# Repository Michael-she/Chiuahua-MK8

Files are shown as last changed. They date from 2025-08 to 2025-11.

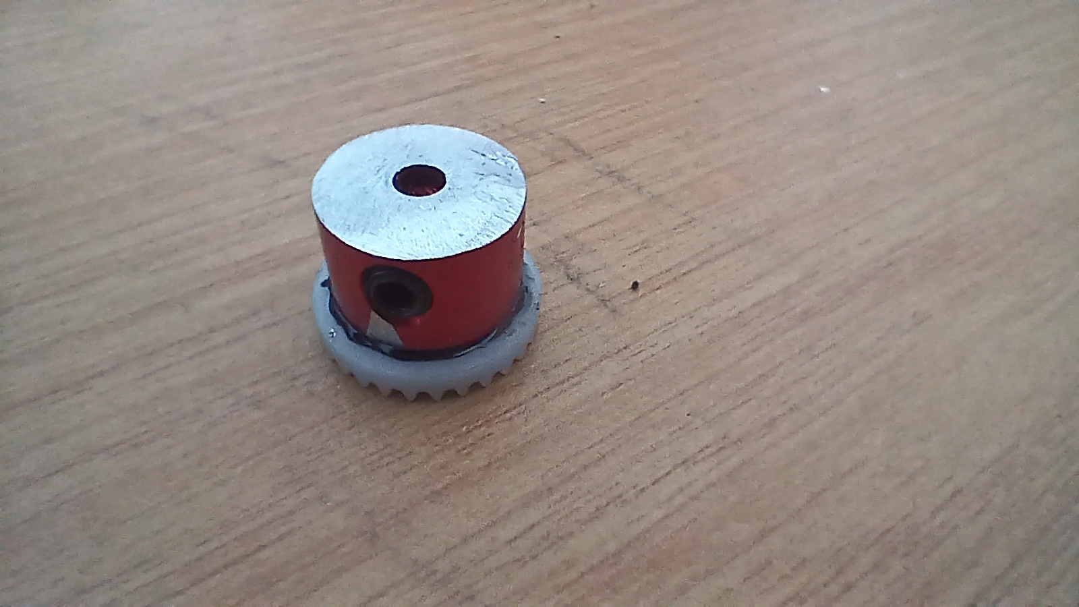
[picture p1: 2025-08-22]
Vehicle-Photos/All/20250713_171845.jpg

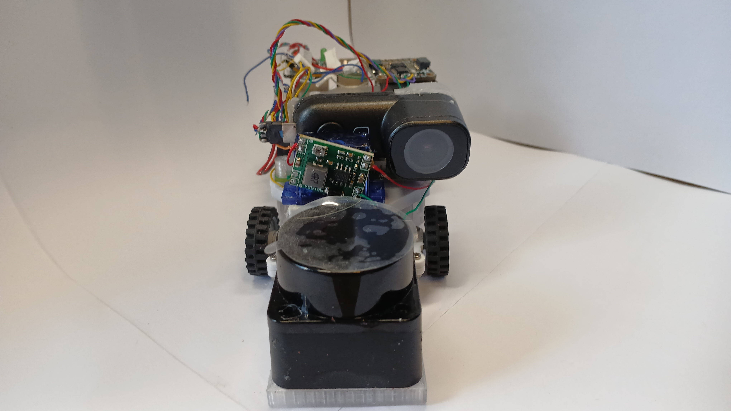
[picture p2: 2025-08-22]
Vehicle-Photos/All/20250822_122142.jpg

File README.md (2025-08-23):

# Chiuahua-MK8 - WRO 2025 Future Engineers Category

Welcome to the Chiuahua-MK8 repository! This project contains all the development work for our autonomous vehicle designed for the World Robot Olympiad (WRO) 2025 competition.

## 📖 Engineering Journal

**👉 Start here: [WRO 2025 Engineering Journal](./Engineering%20Journal/WRO%202025%20JOURNAL.pdf)**

The engineering journal is the comprehensive documentation of our entire development process, design decisions, testing results, and project evolution. It provides detailed insights into:
- Design methodology and iterations
- Technical challenges and solutions
- Testing protocols and results
- Team collaboration and project timeline

## 🗂️ Repository Structure

### 📁 **Engineering Journal/**
Contains the main project documentation:
- `WRO 2025 JOURNAL.pdf` - Complete engineering documentation and project narrative

### 💻 **SRC/** - Source Code
Main codebase for the autonomous vehicle:
- `camera/` - Computer vision and image processing modules
- `final/` - Production-ready code and main control systems
- `gyro/` - Gyroscope sensor integration and orientation tracking
- `lidar/` - LiDAR sensor drivers and obstacle detection
- `motor/` - Motor control and movement systems
- `servo/` - Servo motor control for steering mechanisms
- `Simulation/` - Testing and simulation environments
- `The Taxi/` - Specific challenge implementation code
- `.venv/` - Python virtual environment for dependency management

### 🔧 **3D Models/** - Mechanical Design
CAD files and 3D printable components:
- `STEP/` - Standard 3D model files for manufacturing
- `V1/` - First iteration designs and prototypes
- `V2/` - Second iteration improvements and refinements

### 📋 **3D Printing Profiles/**
Optimized printing settings and profiles for manufacturing vehicle components

### ⚡ **Circuit Schematics/**
Electrical system documentation:
- `Power Map.svg` - Power distribution and electrical layout
- `Schematic_WRO-2025_2025-08-22.svg` - Complete circuit diagrams

### 📸 **Team-Photos/**
Documentation of team members and collaboration

### 🚗 **Vehicle-Photos/**
Visual documentation of the physical vehicle and its development stages

## 🚀 Getting Started

1. **Read the Engineering Journal** - Start with the PDF in the `Engineering Journal/` folder for complete project context
2. **Explore the Code** - Check out the `SRC/` directory for the software implementation
3. **Review Designs** - Look at `3D Models/` and `Circuit Schematics/` for hardware details
4. **See the Vehicle** - Browse `Vehicle-Photos/` to see the physical implementation

## 🛠️ Development Environment

This project uses Python for the main control software. The virtual environment is set up in `SRC/.venv/` with all necessary dependencies.

## 📋 Competition Context

This repository represents our complete solution for the WRO 2025 autonomous vehicle challenge, including:
- Autonomous navigation and obstacle avoidance
- Computer vision for environmental perception
- Sensor fusion for robust decision making
- Real-time control systems for vehicle operation

## 📞 Team Contact

For questions about this project or collaboration opportunities, please contact:
Michael Shepstone - mgshepstone+wrofe@gmail.com
Siobhan Kennedy - skenn23@gmail.com

---

**Note**: This repository contains the complete development history and documentation for educational and reference purposes. The Engineering Journal provides the most comprehensive overview of the project methodology and results.

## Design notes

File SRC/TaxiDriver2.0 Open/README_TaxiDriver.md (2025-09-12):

# Taxi Driver API Documentation

## Overview
The `TaxiDriver` class provides a high-level interface to control a motor using multiprocessing for communication with the motor controller hardware. It uses `multiprocessing.Value` objects for thread-safe communication between the main process and the motor controller process.

## Key Features
- **Motor Speed Control**: Set speed from 0-100%
- **Direction Control**: Forward, reverse, or stop
- **Encoder Feedback**: Real-time encoder count reading
- **Multiprocessing**: Separate process handles GPIO operations
- **Thread-Safe**: Uses multiprocessing.Value for safe data sharing

## Quick Start

```python
from taxi_driver import TaxiDriver
import time

# Initialize taxi driver
taxi = TaxiDriver()
taxi.start_motor_controller()
time.sleep(2)  # Allow initialization

# Basic motor control
taxi.move_forward(50)        # Move forward at 50% speed
time.sleep(2)
taxi.move_reverse(30)        # Move reverse at 30% speed
time.sleep(2)
taxi.stop_motor()            # Stop motor

# Get encoder reading
encoder_count = taxi.get_encoder_reading()
print(f"Encoder count: {encoder_count}")

# Cleanup when done
taxi.cleanup()
```

## API Reference

### Initialization

#### `TaxiDriver()`
Creates a new TaxiDriver instance with multiprocessing communication setup.

```python
taxi = TaxiDriver()
```

#### `start_motor_controller()`
Starts the motor controller process. Must be called before motor operations.

```python
taxi.start_motor_controller()
```

#### `stop_motor_controller()`
Stops the motor controller process. Called automatically by cleanup().

```python
taxi.stop_motor_controller()
```

### Motor Control

#### `set_motor_speed(speed_percent)`
Set motor speed as a percentage.

**Parameters:**
- `speed_percent` (float): Speed from 0-100

```python
taxi.set_motor_speed(75)  # Set to 75% speed
```

#### `set_motor_direction(direction)`
Set motor direction.

**Parameters:**
- `direction` (int): 1=forward, -1=reverse, 0=stop

```python
taxi.set_motor_direction(1)   # Forward
taxi.set_motor_direction(-1)  # Reverse
taxi.set_motor_direction(0)   # Stop
```

#### `move_forward(speed_percent)`
Move forward at specified speed.

**Parameters:**
- `speed_percent` (float): Speed from 0-100

```python
taxi.move_forward(60)  # Move forward at 60% speed
```

#### `move_reverse(speed_percent)`
Move reverse at specified speed.

**Parameters:**
- `speed_percent` (float): Speed from 0-100

```python
taxi.move_reverse(40)  # Move reverse at 40% speed
```

#### `stop_motor()`
Stop the motor immediately.

```python
taxi.stop_motor()
```

### Sensor Reading

#### `get_encoder_reading()`
Get current encoder count.

**Returns:**
- `int`: Current encoder count

```python
count = taxi.get_encoder_reading()
print(f"Encoder: {count} counts")
```

### Status Information

#### `get_motor_status()`
Get comprehensive motor status.

**Returns:**
- `dict`: Status dictionary with keys:
  - `speed`: Current speed percentage
  - `direction`: Direction value (-1, 0, 1)
  - `direction_text`: Human-readable direction
  - `encoder_count`: Current encoder count
  - `status`: Combined status string

```python
status = taxi.get_motor_status()
print(f"Motor: {status['status']}")
print(f"Encoder: {status['encoder_count']}")
```

### Utility Functions

#### `run_test_sequence()`
Run a predefined test sequence demonstrating motor control.

```python
taxi.run_test_sequence()
```

#### `interactive_control()`
Start interactive command-line control interface.

```python
taxi.interactive_control()
```

#### `cleanup()`
Clean up resources and stop motor controller process. Should always be called when done.

```python
taxi.cleanup()
```

## Example Usage Patterns

### Basic Control Loop
```python
taxi = TaxiDriver()
taxi.start_motor_controller()
time.sleep(2)

try:
    # Control loop
    for speed in [25, 50, 75, 100]:
        taxi.move_forward(speed)
        time.sleep(1)
        encoder = taxi.get_encoder_reading()
        print(f"Speed: {speed}%, Encoder: {encoder}")
    
    taxi.stop_motor()
    
finally:
    taxi.cleanup()
```

### Encoder-Based Movement
```python
taxi = TaxiDriver()
taxi.start_motor_controller()
time.sleep(2)

try:
    # Move until encoder reaches certain count
    target_encoder = taxi.get_encoder_reading() + 1000
    taxi.move_forward(50)
    
    while taxi.get_encoder_reading() < target_encoder:
        time.sleep(0.1)
    
    taxi.stop_motor()
    print(f"Reached target encoder: {taxi.get_encoder_reading()}")
    
finally:
    taxi.cleanup()
```

## Hardware Configuration

The motor controller is configured for:
- **Motor Control Pins**: GPIO 20, 21 (PWM control)
- **Encoder Pins**: GPIO 19, 13 (quadrature encoder)
- **PWM Frequency**: 2000 Hz

## Error Handling

Always use try/finally blocks to ensure cleanup:

```python
taxi = TaxiDriver()
try:
    taxi.start_motor_controller()
    # Your control code here
finally:
    taxi.cleanup()
```

## Multiprocessing Details

The `TaxiDriver` uses `multiprocessing.Value` objects for communication:
- `motor_speed`: Double precision float (0-100)
- `motor_direction`: Integer (-1, 0, 1)
- `encoder_value`: Integer (encoder count)
- `shutdown_flag`: Integer (process control)

This design ensures thread-safe communication and isolates GPIO operations in a separate process.

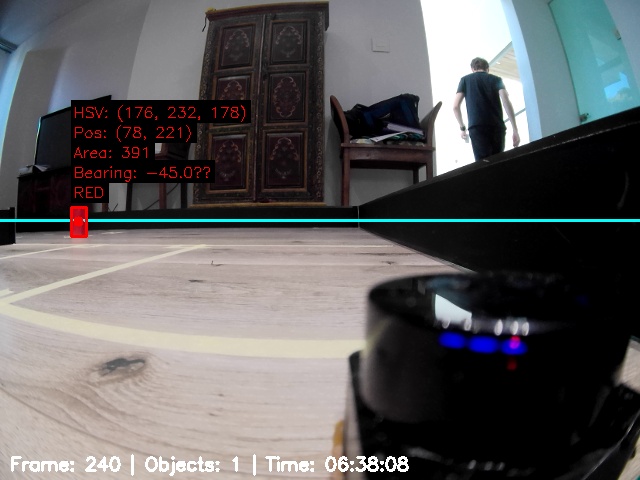
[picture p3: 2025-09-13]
SRC/TaxiDriver4.0 Obstacle/camera_captures/annotated_frame_20250913_063808_000240.jpg

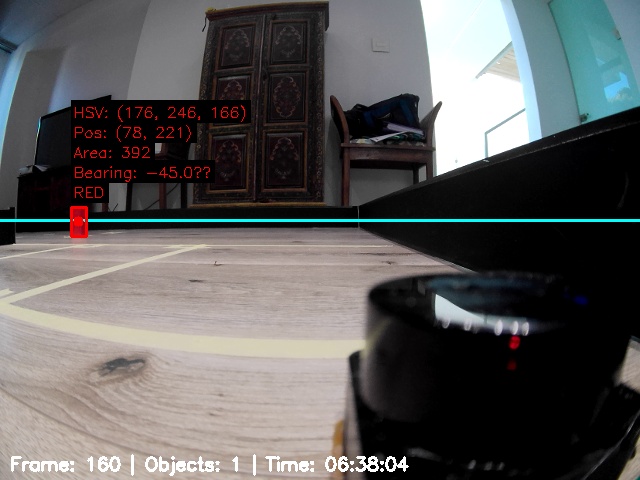
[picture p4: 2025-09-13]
SRC/TaxiDriver4.0 Obstacle/camera_captures/annotated_frame_20250913_063804_000160.jpg

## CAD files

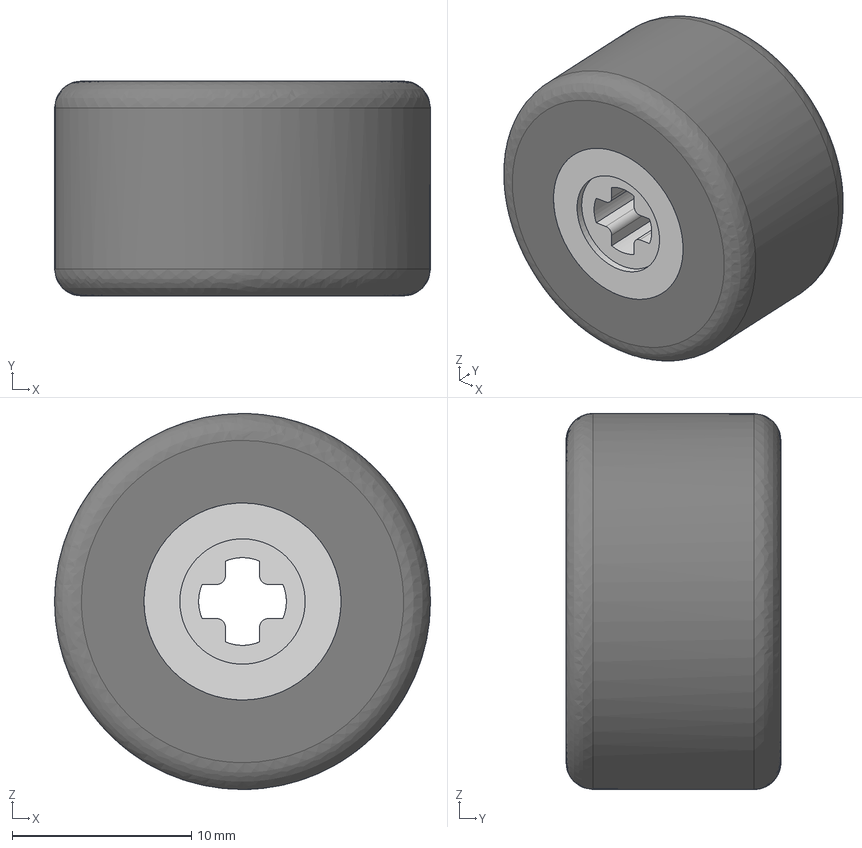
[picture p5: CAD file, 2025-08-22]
3D Models/STEP/Wheel complete v2.iges
21.0 x 12.0 x 21.0 mm

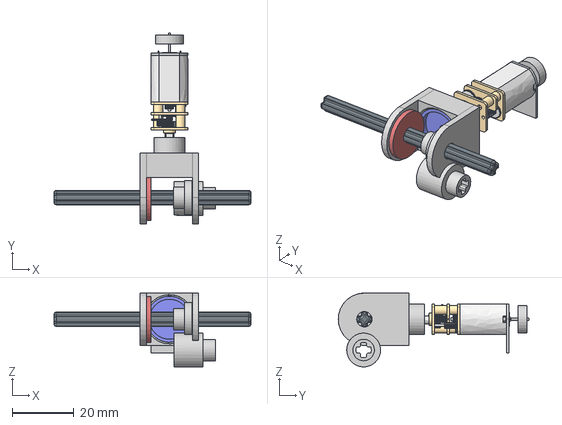
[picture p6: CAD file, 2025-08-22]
3D Models/STEP/Gearbox v15.iges
64.0 x 61.9 x 24.0 mm

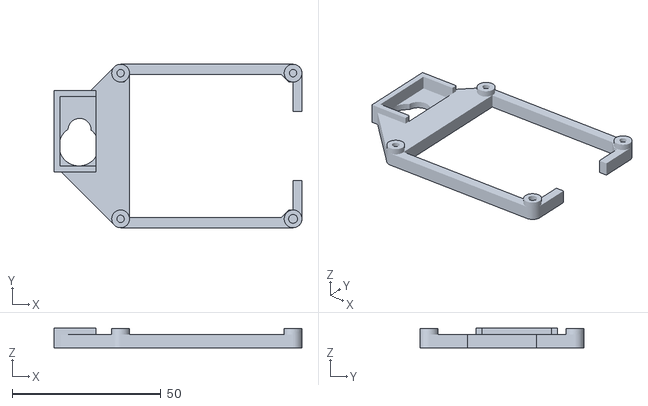
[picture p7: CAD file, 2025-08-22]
3D Models/V2/Pi mount top (2).stl
83.4 x 55.0 x 6.70

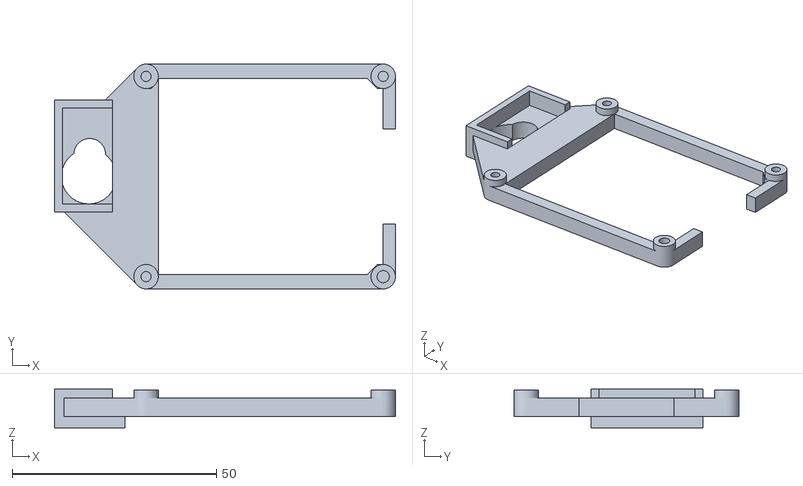
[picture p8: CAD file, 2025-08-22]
3D Models/V2/Pi mount.stl
83.4 x 55.0 x 9.50

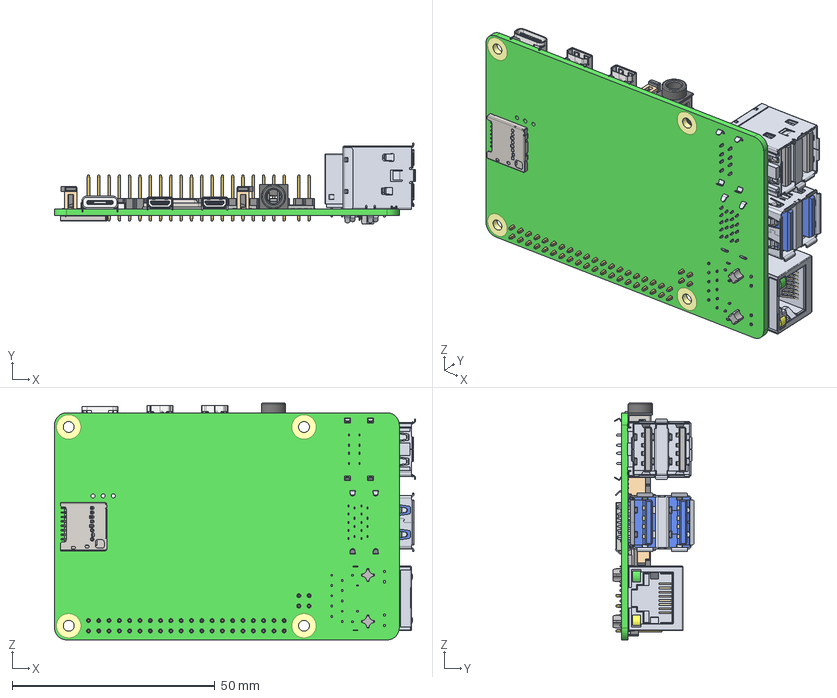
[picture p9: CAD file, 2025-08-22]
3D Models/STEP/Raspberry Pi 4 Model B v1.step
89.0 x 19.9 x 58.4 mm
PCB, RPi4ModelB
Broadcom BCM2711B0 CPU, RPi4ModelB
2.54 mm DUPONT MALE PIN HEADER, POE, 2X2, RPi4ModelB
2.54 mm DUPONT MALE PIN HEADER, IO, 2X20, RPi4ModelB
Camera Connector, RPi4ModelB
Microphone Plug, RPi4ModelB
Display Connector, RPi4ModelB
Gigabit Ethernet Port, RPi4ModelB
Female Micro HDMI Connector, RPi4ModelB x 2
Female USB Type C Connector, RPi4ModelB
2X USB3.0 PORTS, RPi4ModelB
91D77 D9WHV 778K, 4 GB LPDDR4 SDRAM, RPi4ModelB
Cypress CYW43455 Wireless Module Cover, RPi4ModelB
SD Card Slot, RPi4ModelB
VIA VL805 PCIe USB 3.0 controller, RPi4ModelB
2X USB2.0 PORTS, RPi4ModelB
Broadcom BCM54213PE Gigabit Ethernet Transceiver, RPi4ModelB
MxL7704 Universal PMIC, RPi4ModelB

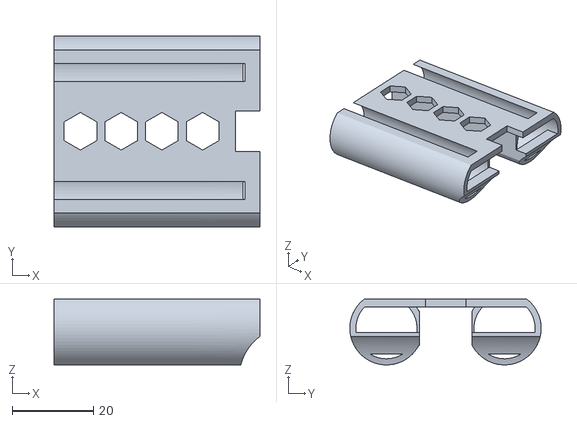
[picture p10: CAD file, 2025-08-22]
3D Models/V2/Battery Holder.stl
50.6 x 47.0 x 16.2

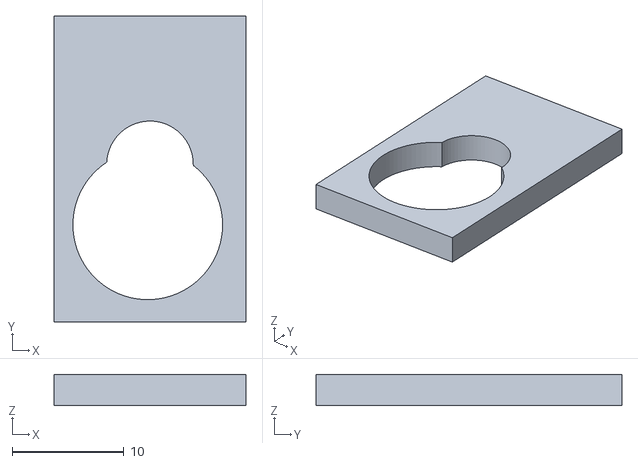
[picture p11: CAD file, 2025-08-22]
3D Models/V2/Pi mount bottom.stl
17.2 x 27.4 x 2.80

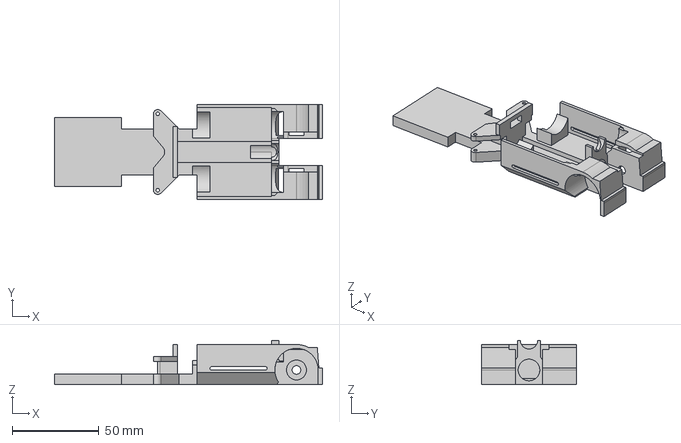
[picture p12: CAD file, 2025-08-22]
3D Models/V2/Frame Unibody.step
154.5 x 55.0 x 25.6 mm

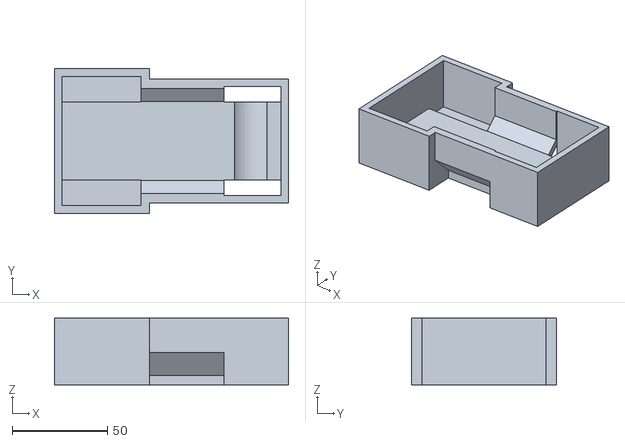
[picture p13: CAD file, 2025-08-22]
3D Models/V2/Component10.stl
122.9 x 76.0 x 35.0

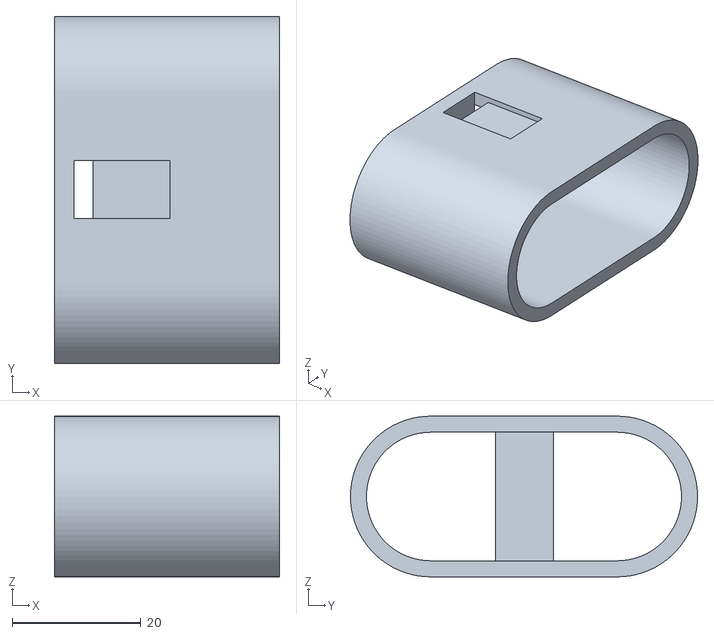
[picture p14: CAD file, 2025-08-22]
3D Models/V2/Battery charger.stl
35.0 x 54.0 x 25.0

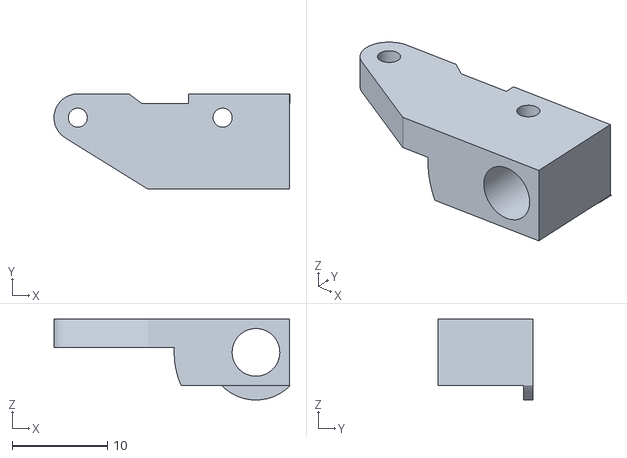
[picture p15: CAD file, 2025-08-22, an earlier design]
3D Models/V1/Front wheel mount.stl
24.8 x 10.0 x 8.50

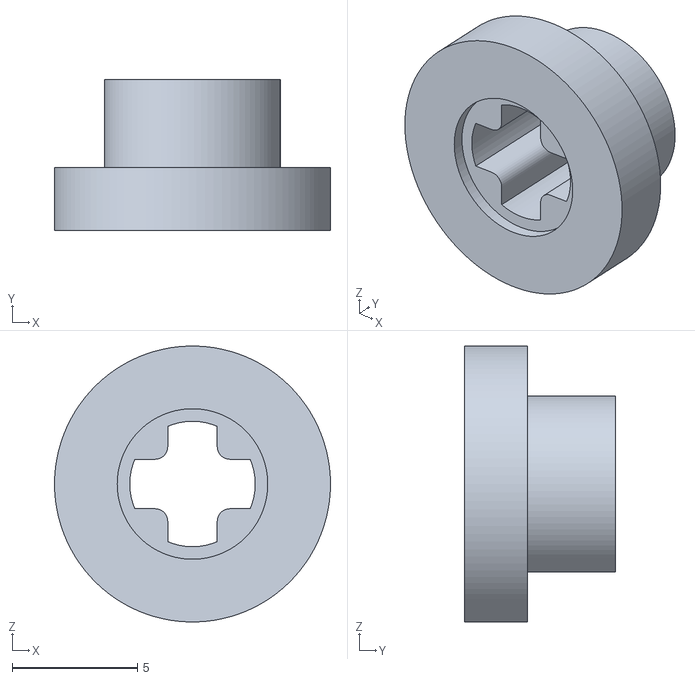
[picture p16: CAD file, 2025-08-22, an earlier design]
3D Models/V1/Gearbox/Axle Gear support type 1 v7.stl
11.0 x 6.00 x 11.0

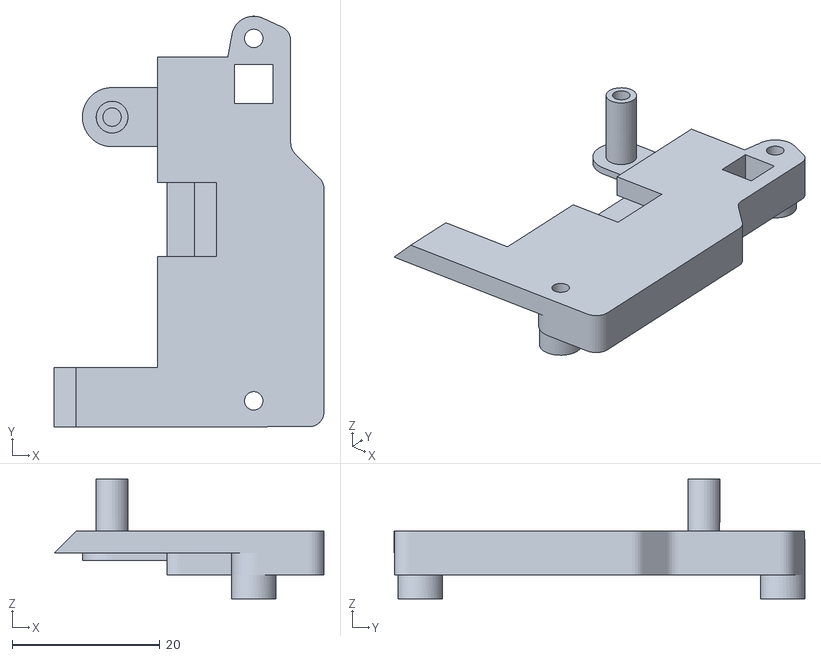
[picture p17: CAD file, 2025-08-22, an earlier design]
3D Models/V1/Top Frame/Body5.stl
36.5 x 55.5 x 16.2

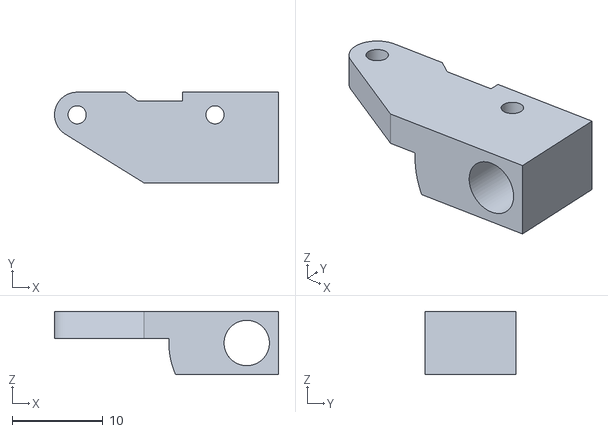
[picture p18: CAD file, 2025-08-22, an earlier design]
3D Models/V1/Front wheel mount R.stl
24.7 x 10.0 x 7.00

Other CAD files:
3D Models/V1/Gearbox/Gearbox casing.stl
3D Models/V1/Top Frame/Body6.stl
3D Models/V1/Battery Holder.stl
3D Models/V1/Gearbox/Motor Shaft.stl
3D Models/STEP/13500 cell v1.f3d
3D Models/STEP/Battery Holder.f3d
3D Models/STEP/Frame Unibody.f3d
3D Models/STEP/Front wheel mount R.f3d
3D Models/STEP/Front wheel mount(Mirror).f3d
3D Models/STEP/Motor Driver.f3d
3D Models/STEP/OKDO Lidar v2.f3d
3D Models/STEP/Pi mount.f3d
3D Models/STEP/RunCam Thumb v4 v1.f3d
3D Models/STEP/Steering bar.f3d
3D Models/STEP/Upper frame.f3d
3D Models/STEP/Wheel 2 v1(Mirror).f3d
3D Models/STEP/Wheel 2 v1.f3d
3D Models/STEP/microservoAssembly v3.f3d
3D Models/V1/Body19.stl
3D Models/V1/Component5.stl
3D Models/V1/Component6.stl
3D Models/V1/Frame Unibody.stl
3D Models/V1/Front wheel mount(Mirror).stl
3D Models/V1/Pi mount top.stl
3D Models/V1/Steering bar.stl
3D Models/V1/Top Frame/Body10.stl
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

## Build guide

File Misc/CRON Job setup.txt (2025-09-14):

Go and create the CRON JOB To run on reboot. 
Run the command
>> crontab -e

Add line in the format:
@rebo1ot [path to python], [path to script]

    @reboot /usr/bin/python3 /home/ubuntu/active/taxi_navigator.py >> /logs/logfile.log 2>

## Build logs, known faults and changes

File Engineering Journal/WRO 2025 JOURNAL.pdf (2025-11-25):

# WRO 2025 ENGINEERING JOURNAL

# Future Engineers

# Team: NullPointerException

# Contents

# Introduction

Welcome to team NullPointerException’s Engineering Journal. This document will guide you through our process of designing, building and programming our robot. Along with this will be demonstration videos of the final version, pictures, and step by step instructions for its assembly.

This year’s Self-Driving Car challenge features a reintroduction of the randomisation process, a removal of the need to turn around in the last round, and adjusted rules concerning parallel parking. Basing our current robot off its counterpart used in last year’s challenge, this document will describe the revisions and reworks we have applied to comply with the added features of the challenge, as well as improve its overall functionality.

# The Team

We are a South African team, made up of:

❖ Michael Shepstone (20) - studying Mechatronic Engineering

❖ Siobhan Kennedy (20) - studying Computational Linguistics

❖ Jarred Williams - our coach

And of course, Chihuahua (the robot).

Chihuahua has seen many improvements and evolutions over the last three years of partaking in the World Robotics Olympiad’s Future Engineers category, with this document describing its latest version, version 8.5.

Coming out of last year’s competition, we learnt numerous lessons and brought new ideas to the table on how to improve our robot this time around. Ultimately, we decided to go back to the drawing board for the most part. In our mission to rehaul the robot, we discovered more efficient ways to make the robot function better, while also learning several important lessons, which are elaborated on throughout the document.

Michael Shepstone and Siobhan Kennedy

## “Chihuahua” Mk8

Picture 1: Front view | Picture 2: Back view
Picture 3: Left side view | Picture 4: Right side view
Picture 5: Top view | Picture 6: Bottom view

# Mobility Management

## POWERTRAIN

### Wheels and Tyres

We used Lego rubber tyres (part number 60700) for the back wheels, and Lego rubber wheels and hubs (part numbers 61254 and 56902) for the front wheels. We learned that the wheels needed to be rubber for better grip and to avoid slipping. Lego makes rubber wheels that were perfectly suited to the adjustments we wanted to make.

The tyres used for the back wheels were chosen due to their large width-to-diameter ratio, as well as their good grip. This ensures that the robot can remain sturdy while travelling across the surface and prevent any slipping. For whatever reason, lego makes no wheel hub for this particular tyre that can fit an L-series axle, thus we had to design and print our own.

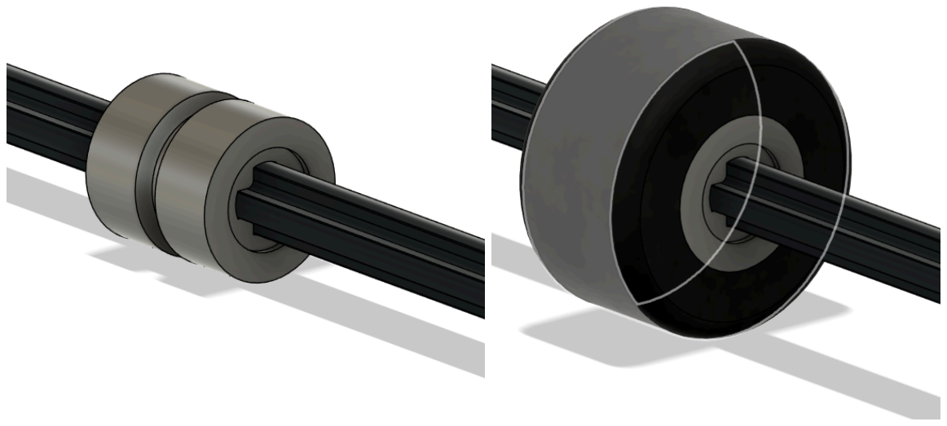
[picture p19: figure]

Diagram 1 & 2: Wheel adaptor on shaft, without and with tyre

The tyres we used for the front wheels are relatively narrow, which causes high loading, which in turn reduces the clearance required for the robot to be able to steer smoothly. These wheels rotate freely.

### Gearbox and Drivetrain

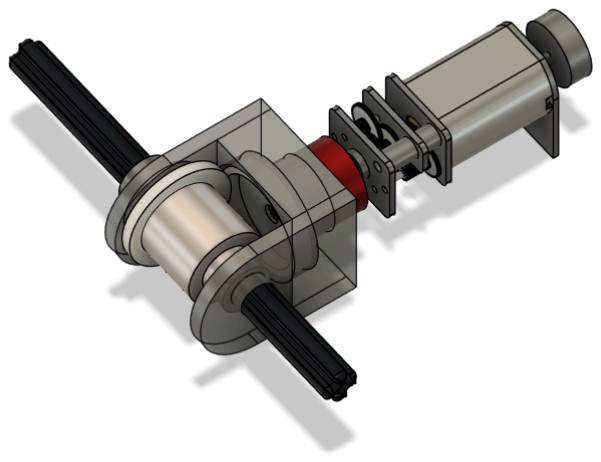
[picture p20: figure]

Diagram 3: CAD Model of the complete motor-gearbox-axle assembly

The robot’s drivetrain currently consists of a lego L-series axle, and two gears that transfer the power by 90 degrees. To achieve this, the motor coupler has been cut in half, with the gear glued to it. This gear then meshes with a separate gear at a 90 degree angle to it. This second gear transfers the motion to the axle.

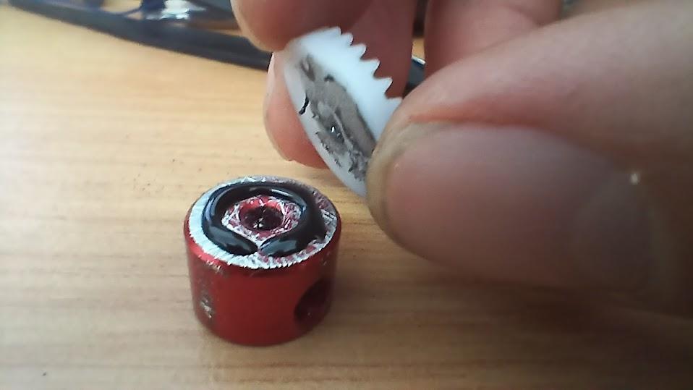
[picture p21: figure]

Picture 7: Attaching the gear to the halved motor coupler

Based on previous versions of the robot, we learned that ultimately, it was best to keep the wheel and axle system simple. We also previously attempted using a differential gearbox, but found that it was too large, and could easily cause problems should a wheel break ground contact.

### Motor

Diagram 4

After considering various different motors, we settled on an N20 motor with an 800 rpm gearbox, (https://www.robotics.org.za/N20-800RPM-KIT?search=N20) with the following specifications:

- Voltage: 12V
- Weight: 9.5g
- Gear Ratio: 1:50
- Speed: 650 ± 31% rpm
- Torque: 0.67 ± kg∙cm

Other motors we considered include:

- Micro Stepper motors – Very precise, easy to drive with good power output, but was too large and outside the
required RPM range.
- Where to buy the motor:

https://www.robotics.org.za/index.php?route=product/product&product_id=1438&search=stepper (https://www.robotics.org.za/index.php?route=product/product&product_id=1438&search=stepper)

- 130 Size DC Motors – Cheap and easy to obtain, with many pre-assembled attachments, but ended up being too underpowered and electronically noisy. Plus, it would have required an additional gearbox in any case.
- Where to buy the motor:

https://www.robotics.org.za/DC-MOTOR-6V?search=6v

- 25mm DC Motors – Good power output with an included gearbox, the motor of choice for previous robots, but ended
up being too large in this case.
- Where to buy the motor:

https://www.robotics.org.za/25GM370-060-12V?search=DC%20motor

Ultimately, we decided on the N20 800rpm motor for its lightweight and compact design. As this motor did not come with an encoder attached, we ended up using a 15rpm motor with the 800rpm motor transferred onto it.

Our encoder of choice is a Hall-effect magnetic encoder, which offers high precision and encodes direct motor output. In order to fit it into our robot, it had to be filed down, and the connector had to be removed with wires soldered directly to the PCB.

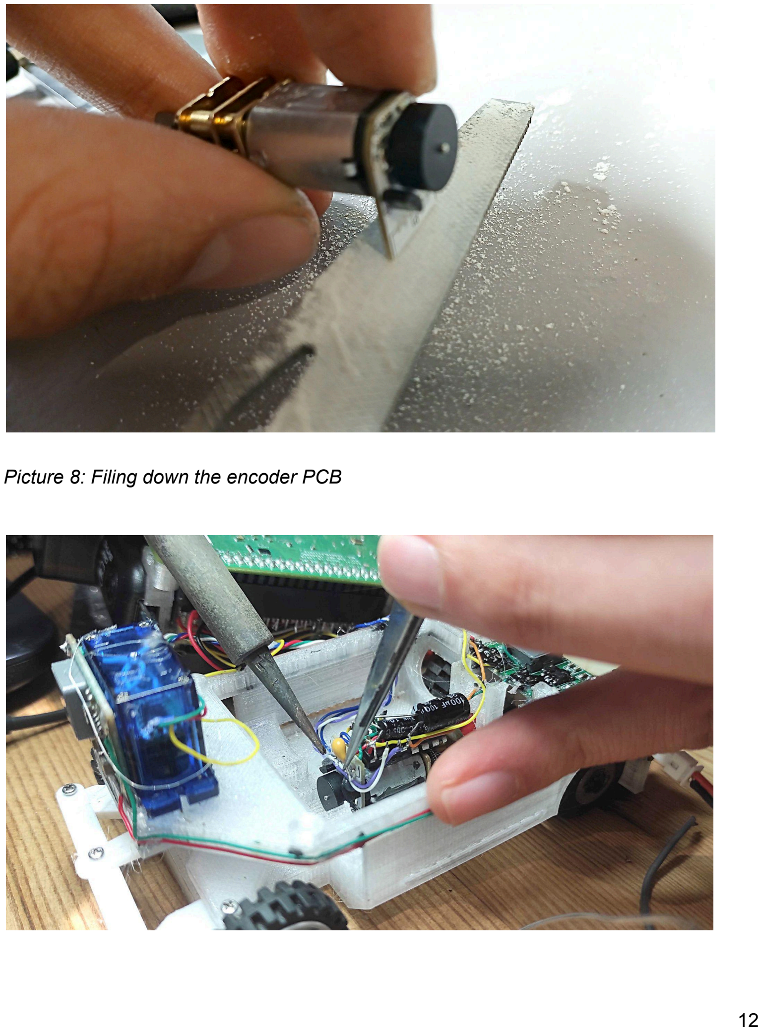
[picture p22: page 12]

Picture 8: Filing down the encoder PCB

Picture 9: Soldering wires to the motor and motor driver

This motor connects directly to the aluminium motor coupler that is glued to the gear. The motor shaft is secured in place with a grub screw, instead of glue. Not only does this allow for a slight tolerance in the placement of the motor, but it also allows for parts to be swapped out, should it be necessary.

The previous iteration of this robot had a 3D printed driveshaft, which ended up proving to be problematic as it was prone to stripping or shearing. Therefore, based on the lessons learnt, all of our driveshafts are made of injection molded, or metallic components.

### Motor Driver

For this iteration of the robot, we elected to use the MX1919 motor driver chip, (https://www.robotics.org.za/MAX1919-DIP?search=MX1919) with the following specifications:

- Power Supply Voltage:
- Min: 2V
- Max: 9.6V
- Logic and Control Supply Voltage:
- Min: 1.8V
- Max: 5V
- Integrated Bridge Drive Circuit

The chip was attached to the motor backwards, and wires were soldered directly to the driver. Its feet were also clipped short for spatial efficiency.

A very important lesson we learned from this part of the assembly process was that the motor driver must be wired with capacitors in order to prevent accidentally blowing the chip. We will not be disclosing how we discovered this, but you can probably guess.

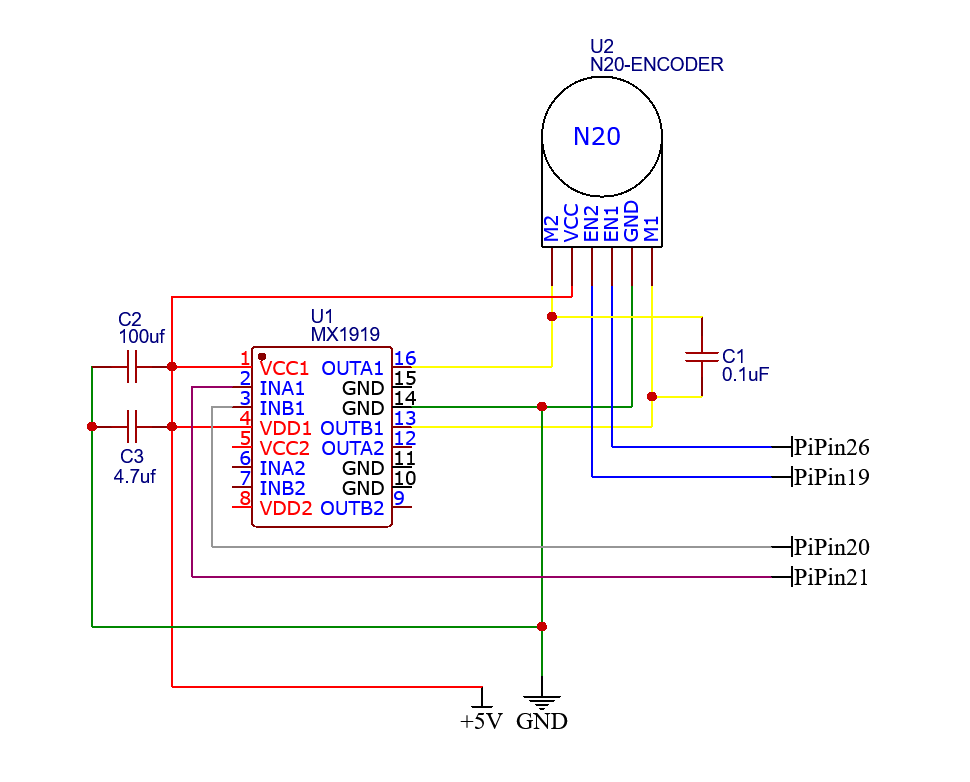
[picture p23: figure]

Diagram 5: Schematic for motor driver

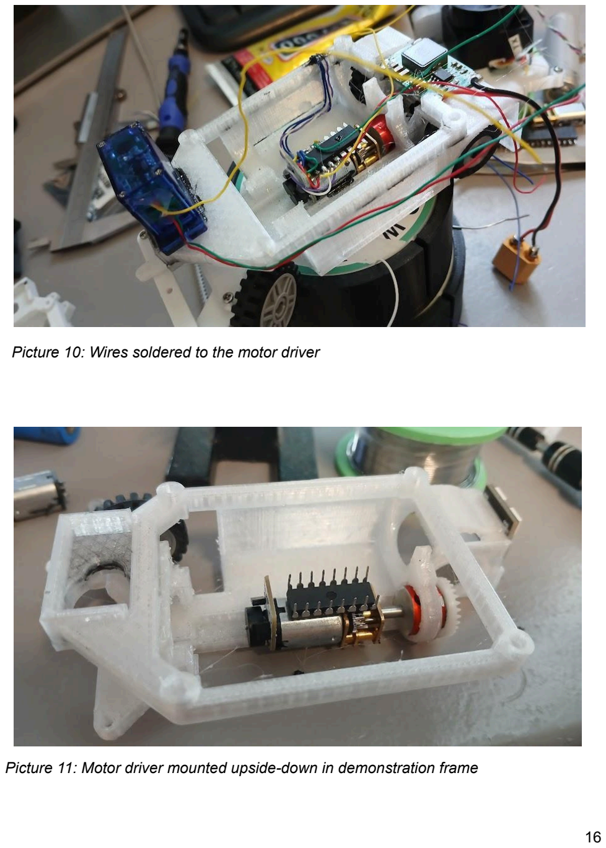
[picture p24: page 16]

Picture 10: Wires soldered to the motor driver

Picture 11: Motor driver mounted upside-down in demonstration frame

## STEERING

### Motor

For our steering motor, we opted to use the FS90 9g Analog Servo, (https://www.robotics.org.za/FS90?search=Servo) with the following specifications:

- Closed loop (180 degrees)
- Torque: 6V:1.5 kg∙cm
- Operating Voltage: 4.8V - 6V
- Speed: 6V:0.10 sec/60°
- Size: 23.2 * 12.5 * 22.0mm

Ultimately, we chose this motor for its positional encoding. Additional factors include its cost efficiency, ample library support, and more-than-sufficient power output required to drive the steering system. At one point we considered using a stepper motor for its precision, but decided against it. In comparison to the servo motor, the stepper motor is slower, and requires a “homing” sequence (or some other form of external encoder) in order to learn its position. This is less effective than the positional encoding of the servo.

### Mechanism

For last year’s competition, the robot used an “all wheel” steering system which, while getting the job done at the time, proved to be problematic. This year, we circumnavigated these issues by employing a simple “front wheel only” steering system instead.

Based on previous experience, we knew from the start that minimising the turning radius would be vital to the success of the robot. The “all wheel” system used in previous versions of the robot was simply not worth the complexity and the single points of failure it caused, and thus, another method was needed.

To accomplish this, the robot now uses a steering bar driven by the arm of the servo to manipulate the front wheel mounts, so that they can move left and right with a ± 45 degree angle of steering. The linkages are made using m1.5 bolts and nuts, the latter of which are secured with hot glue to prevent vibrations from losing them and adding “slop” to the mechanism.

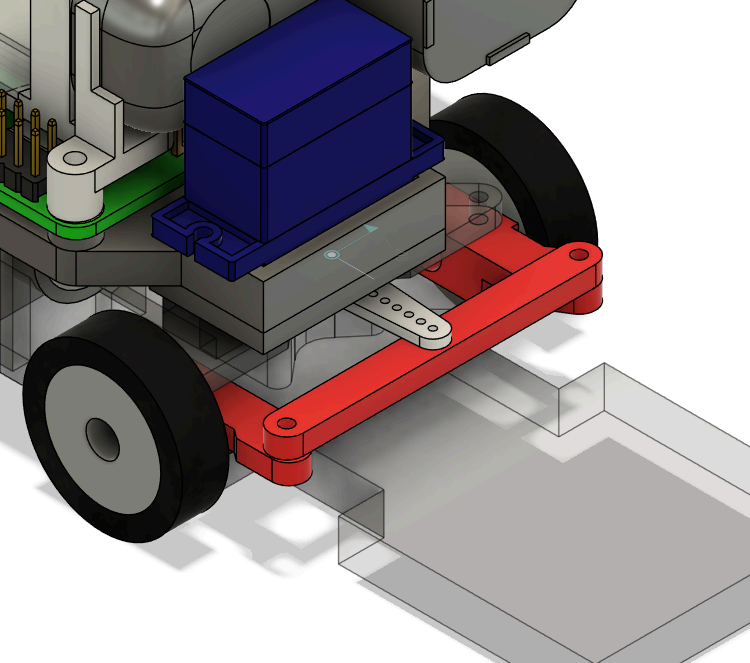
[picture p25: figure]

Diagram 6: Simplified steering mechanism highlighted in red

### Wheel Base

The final turning radius of a robot is directly proportional to the wheelbase of a robot, therefore this must be kept to an absolute minimum, the wheelbase of this robot is 70mm, which is tiny compared to the 110mm wheelbase of the previous iteration. This was achieved by shrinking the entire robot, and packing components as close together as possible, internally. Additionally, only components that were physically unable to be placed elsewhere were put between the front and back wheels.

### Wheel Separation

Due to the lack of a differential drive, the back wheels spin at the same speed, resulting in one being “dragged” over the mat when the robot is turning. Therefore, the distance between these wheels needs to be kept to a minimum in order to minimise the moment of torque this creates.

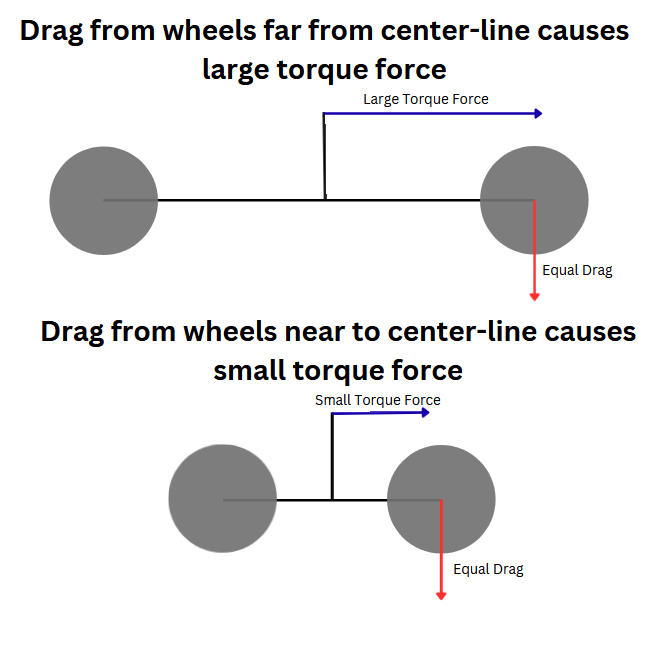
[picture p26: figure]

Diagram 7: Reasoning for chosen distance between wheels

Conversely, the distance between the front wheels must be maximised relative to this, to maximise the torque they put on the robot to turn it, ensuring that the robot turns properly when commanded to do so.

## CHASSIS

The chassis of our robot is entirely 3D printed from a mixture of PTEG and PTA filament, with PTEG (chosen for its resistance to becoming brittle, high strength and relative ease of printing) being used for the major components, and PTA (used for its high dimensional accuracy, and ease of printing) being used for smaller and non-critical components.

The chassis consists of two main layers: above and below the Raspberry Pi. The Raspberry Pi, spanning the full width of the robot and the majority of the usable length, essentially splits the robot in two.

The main unibody frame is printed as a single piece, simplifying the robot and reducing the required assembly. This frame houses the motor, motor driver, and the battery pack. It provides mounting points for the steering servo, LiDAR, voltage regulators, and the Raspberry Pi.

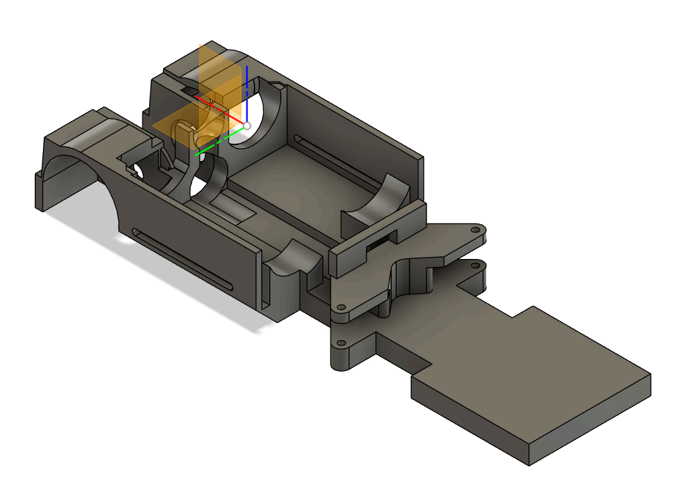
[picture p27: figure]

Diagram 8: Main frame

There are still some pieces that need to be assembled to create the main frame. These parts were separated to remove large overhangs that would otherwise need to be printed.

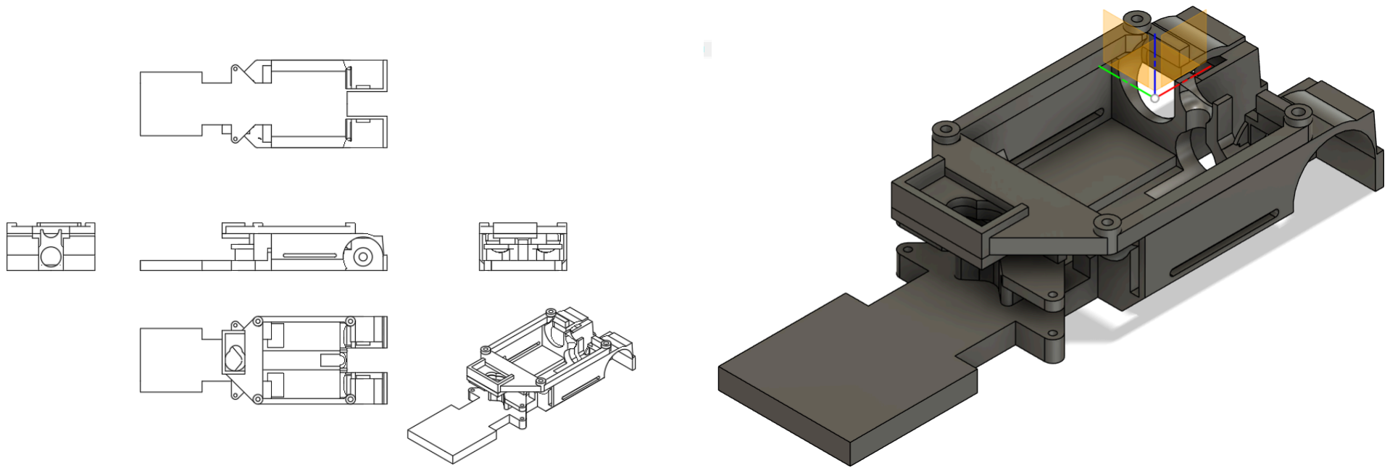
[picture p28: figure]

Diagrams 9 & 10: Blueprint for main frame

This frame houses all of the components occurring below the Raspberry Pi.

Above the Pi, a second “frame” is present, connected to the rest of the vehicle by a series of pins, allowing for toolless removal and easy access to the components below. This upper-frame provides mounting points for the camera, gyroscope and other associated components.

Based on past experience, we decided that we needed to keep the size of the frame to a minimum, particularly in width, in order to allow for the maximum tolerance for error between the robot and the obstacles.

The components used for the chassis were printed using an ender 3 V2 Neo and an Ender 3 S1 Pro, with the following settings:

Cura Profile link (https://github.com/Michael-she/Chiuahua-MK8/tree/main/3D%20Printing%20Profiles)

Parameter | Value
Wall Width | 0.8
Print Speed | 60mm/s

Infill | 20%
Top/bottom thickness | 0.5mm
Printing Temperature | 200C-235C
Build Plate Adhesion | Skirt
Support | Tree

## LIST OF MATERIALS

1x Raspberry Pi 4B | Purchase Link (https://www.communica.co.za/products/raspberry-pi-4b-4gb?variant=29953457160265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)
1x OKDO LD06 LiDAR Module | Purchase Link (https://www.yoink.co.za/product/waveshare-d300-developer-kit-dtof-laser-ranging-sensor-360-omni-directional-lidar-uart-bus/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)
1x Runcam Thumb Pro | Purchase Link (https://www.bobshop.co.za/thumb-pro-4k-v2-bigger-new-version-mini-action-camera-16g-bulit-in-gyro-wide-angle/p/651079590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)
1x BNO08X Gyroscope | Purchase Link (https://www.adafruit.com/product/4754)
1x 9g Servo | https://www.robotics.org.za/FS90?search=servo (https://www.robotics.org.za/FS90?search=servo)
2x 5V 5A Buck Convertors | https://www.robotics.org.za/ND1805TA-5V?search=5v%205a (https://www.robotics.org.za/ND1805TA-5V?search=5v%205a)
1x 3V Low Profile Relay Module | https://www.robotics.org.za/ALDP105W?search=slim%20relay (https://www.robotics.org.za/ALDP105W?search=slim%20relay)
2x 14500 Li-on cells | https://www.robotics.org.za/14500-1000MAH-FLAT?search=14500 (https://www.robotics.org.za/14500-1000MAH-FLAT?search=14500)
2x lego tyres (get number) | Generic
2x other tyres (get number) | Generic
1x MX1919 Motor Driver | https://www.robotics.org.za/MAX1919-DIP?search=MX1919%20 (https://www.robotics.org.za/MAX1919-DIP?search=MX1919%20)

1x N20 Motor (with encoder) (800rpm) | https://www.robotics.org.za/MAX1919-DIP?search=mx1919 (https://www.robotics.org.za/MAX1919-DIP?search=mx1919)
1x USB-A Male Header | https://www.robotics.org.za/MICRO-USB-50?search=USB&page=2 (https://www.robotics.org.za/MICRO-USB-50?search=USB&page=2)
1x USB-micro Male Header | https://www.robotics.org.za/MICRO-USB-50?search=USB&page=2 (https://www.robotics.org.za/MICRO-USB-50?search=USB&page=2)
2x 2x2 NeoPixel LED Array | https://www.robotics.org.za/SW602?search=LED&page=2 (https://www.robotics.org.za/SW602?search=LED&page=2)
1x L-Series Lego Shaft. | Generic
1x 2x20 pin female 2.54mm headers | https://www.robotics.org.za/HF-2X40-254-SMD?search=2.54mm%20female (https://www.robotics.org.za/HF-2X40-254-SMD?search=2.54mm%20female)

### Various

Plastic Gears

https://www.aliexpress.com/p/tesla-landing/index.html?productId=1005005028622826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 (https://www.aliexpress.com/p/tesla-landing/index.html?scenario=c_ppc_item_bridge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) ff_short_key=_oFgTQeV&gclsrc=aw.ds&

&albagn=888888&&ds_e_adid=&ds_e_m atchtype=&ds_e_device=c&ds_e_network =x&ds_e_product_group_id=&ds_e_prod uct_id=en1005005028622826&ds_e_pro duct_merchant_id=490772150&ds_e_pro duct_country=ZA&ds_e_product_languag e=en&ds_e_product_channel=online&ds_ e_product_store_id=&ds_url_v=2&albcp= 22473124773&albag=&isSmbAutoCall=fa lse&needSmbHouyi=false&gad_source=1 &gad_campaignid=22483079722&gclid= Cj0KCQjwqqDFBhDhARIsAIHTlkvZ-nLwiI J_8Q1qv4C6r0kEKM8HiuotF28C_L70Kls 4pCXq1gAzfRwaAqjSEALw_wcB (https://www.aliexpress.com/p/tesla-landing/index.html?scenario=c_ppc_item_bridge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)

M1.25 bolts and nuts

https://www.aliexpress.com/p/tesla-landing/index.html?productId=1005004949292330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 (https://www.aliexpress.com/p/tesla-landing/index.html?scenario=c_ppc_item_bridge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) ff_short_key=_oFgTQeV&gclsrc=aw.ds&

&albagn=888888&&ds_e_adid=&ds_e_m atchtype=&ds_e_device=c&ds_e_network =x&ds_e_product_group_id=&ds_e_prod uct_id=en1005004949292330&ds_e_pro duct_merchant_id=107800437&ds_e_pro duct_country=ZA&ds_e_product_languag e=en&ds_e_product_channel=online&ds_ e_product_store_id=&ds_url_v=2&albcp= 22473124773&albag=&isSmbAutoCall=fa lse&needSmbHouyi=false&gad_source=1 (https://www.aliexpress.com/p/tesla-landing/index.html?scenario=c_ppc_item_bridge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)

| &gad_campaignid=22483079722&gclid= Cj0KCQjwqqDFBhDhARIsAIHTlks0i_AP4 GOqXtTKE9eXDS9EUYC8dXF1ibQBP2s kP2IvWMuAbXWpeSkaAhz6EALw_wcB (https://www.aliexpress.com/p/tesla-landing/index.html?scenario=c_ppc_item_bridge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)
PLA/PTEG Filament | Generic
Wrapping wire | Generic
Solder | Generic

# Power and Sense Management

Diagram 11: Power Distribution map

## BATTERY PACK

This version of the robot uses two batteries: an internal battery and an external battery. Due to the internal battery lasting about 45 minutes, the robot is commonly connected to an external battery pack while writing code. In our case, this is a 5000Mah 12V LiPo battery, but any large battery or power supply is suitable, provided it can produce the necessary current.

For the internal battery, we are using a custom battery pack assembled from 2 x 14500 Lithium Ion (Li-on) battery cells, (https://www.robotics.org.za/14500-1000MAH-FLAT?search=14500) and wired with a 1mm pitch JST XH connector. This gives us 1000mah of capacity at a nominal voltage of 7.2V. These batteries were chosen for their small size and high energy density.

As a result of the custom shape and connections of our internal battery pack, we had no way to charge these batteries safely using a commercially available charger. Therefore, a charging “frame” needed to be built. This is able to adapt the battery to the typical

XT-60 and JST XH connectors of a Lithium-Ion Polymer (LiPo) battery. This allows the battery to be safely charged using a 2 cell LiPo charger.

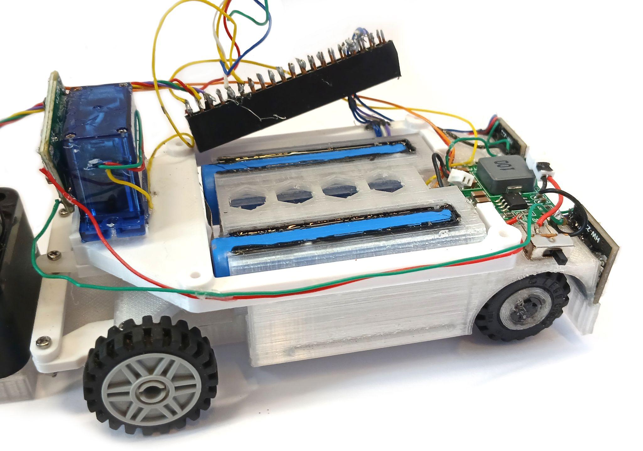
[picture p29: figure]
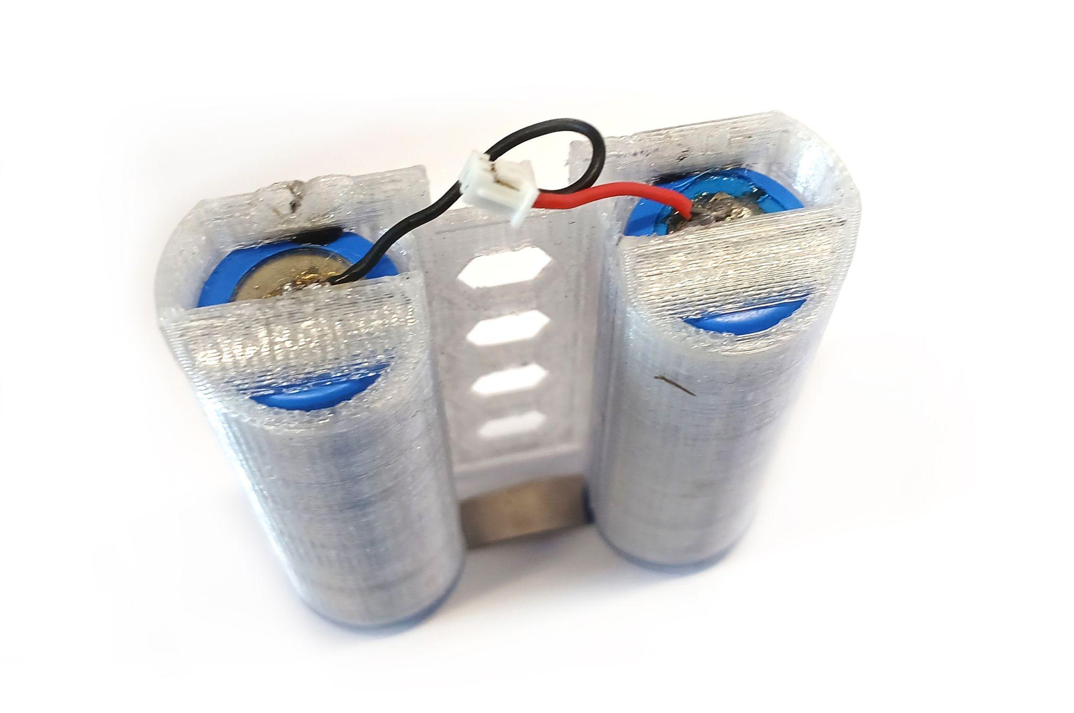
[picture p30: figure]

Pictures 12 & 13: Battery Pack installed in the robot, and standalone

## VOLTAGE REGULATION

We used 2 x 5A fixed 5V buck converters (https://www.robotics.org.za/ND1805TA-5V?search=5V%205A) for voltage regulation. These drop the 7.2V battery down to the 5V that is used by the remainder of the robot.

Initially there was only a single voltage regulator, but although theoretically possible, the Raspberry Pi and servo sharing a power supply made the servo act erratically. Therefore, we split the power circuits.

## RASPBERRY PI

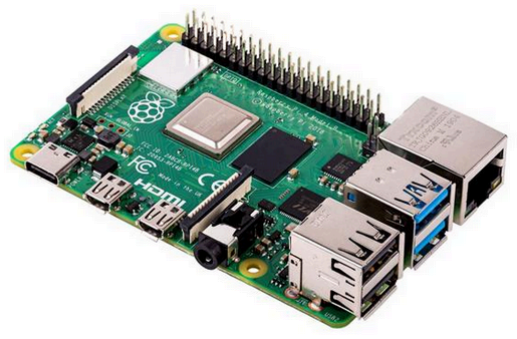
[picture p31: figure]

All the sensors are managed by a Raspberry Pi 4B (https://www.pishop.co.za/store/raspberry-pi-4-model-b-4gb) running Raspbian, which we chose because of its processing power and ability to run multiple processes in parallel. Each sensor is assigned a process in code to ingest and process raw data. This data is then made available to the main program to be retrieved as needed.

This is a far simpler set-up than our previous robot, which used multiple microcontrollers to manage each process (with one core being assigned one process, and data being passed between boards using an I2C bus). This ended up resting multiple single points of failure, where loose wires or an excess of EMI would cause the robot to fail.

## LiDAR

The sensors on our robot use LiDAR, (https://za.rs-online.com/web/p/sensor-development-tools/2037609) which shoots out a beam of light at a known angle. Based on the time the reflected light takes to return, it can calculate the distance to that point on a potential object.

The sensor rotates 5 times per second, with 300 points per rotation. Therefore, you can determine the position of a point relative to the robot, based on its angle in relation to the robot and its distance from it. With enough of these points, you can assemble a dynamic “map” of the robot's surroundings, thereby constantly reading its position.

## GYROSCOPE

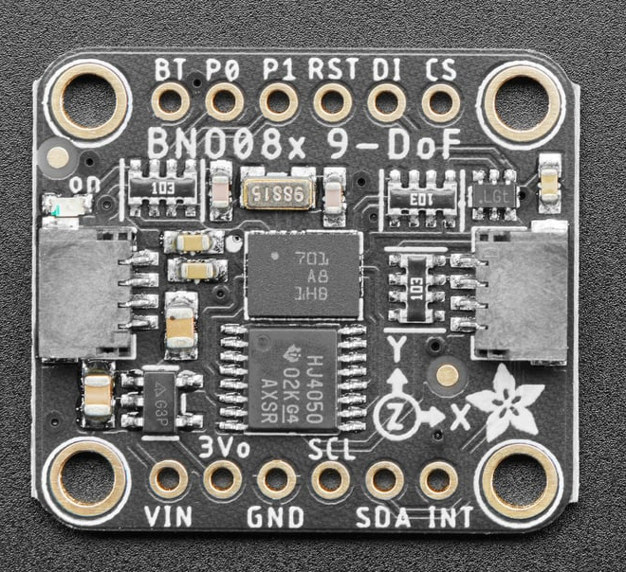
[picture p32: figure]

This robot utilises a BNO08X gyroscope, (https://www.adafruit.com/product/4754) mounted to an Adafruit development board. This board is capable of internal sensor fusion to output a highly accurate absolute angle. Communication with this board occurs over an I2C bus.

## CAMERA

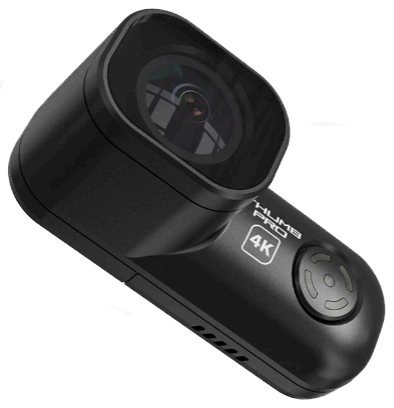
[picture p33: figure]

The camera used is a RunCam Thumb Pro. (https://www.ebay.com/itm/364603400683?chn=ps&google_free_listing_action=view_item) This is typically used as an action camera on first person view (FPV) drones.

This camera was chosen due to its 150 degree field of view, small and compact size, and its USB output.

This choice of camera does present a major issue though: When connected to USB, its default state is to act as a USB drive. It needs to be placed into “camera mode” by pressing the button on the camera. In this mode, it acts as a USB webcam.

Pressing this button proved to be a challenge, with our final solution being to use a relay and connections directly to the camera board to simulate the effects of a button press.

# Obstacle Management

The robot runs the exact same program for both the open challenge and the obstacle challenge.

Initially, we attempted to use a Simultaneous Localisation and Mapping (SLAM) algorithm. This algorithm would have allowed the robot to map its surroundings, while using that same, potentially half built map, to navigate and make intelligent decisions. If we had been able to get this to work, it would have provided an ideal, self-recovering solution to the challenge. Unfortunately, it did not work, and thus we had to go back to the drawing board.

During our attempts at this algorithm, an additional challenge was noted: If the robot leant slightly to one side, the LiDAR sensor would look over the track boundaries and into whatever was beyond. This is suboptimal, as it would allow an object beyond the track boundaries to influence the navigation and decision making process of the robot.

To address these challenges the LiDAR sensor was placed in front of the robot in a lower position. This resulted in a far greater acceptable margin of error (in terms of robot altitude) before the sensor potentially looks over the walls, or at the floor of the track. Although this limits the field of view that the LiDAR sensor has access to (to about 200 degrees as opposed to the 360 degrees previously possible, this drawback is massively outweighed by the ability to almost absolutely trust that the readings from the LiDAR are from a relevant object.

The current method of obstacle avoidance and navigation divides the track into 4 equal “segments”. The track is divided by two lines that run at 45 degrees between opposite corners of the outside wall. Segment 1 is defined as the segment in which the robot starts. The segments are then numbered increasingly depending on the order in which the robot will arrive at them. These segments are used as a navigation aid only, allowing the robot, assuming it knows which segment it is in, to pinpoint its exact position on the mat.

Diagram 12: “Segmented” map

## SETUP

In our current algorithm, the robot scans the starting area upon boot, attempting to look for walls using the RANSAC algorithm.

1) Ideal scenario - three walls identified via RANSAC
- If three walls are found (front, left and right), the robot can determine its starting point. There are only 6 possible open challenge starting points, and 2 obstacle challenge starting points. The code will “snap” the “starting” position of the robot to the middle nearest one, but keep its estimated position at the observed position.
2) Suboptimal scenario - less than three walls are detected
- If less than three walls are detected in all directions on a multiple 90 degrees that do not have a wall detected with RANSAC, the robot casts a ray until it finds a point within a set distance within that ray. This is then taken to be the distance between the robot and the wall.

The vehicle then attempts to determine the direction in which it will need to turn. This is done by comparing the lengths of the walls to the left and right, with the robot needing to turn in the direction of the shorter wall.

1) Ideal scenario - from the starting point the robot can determine which direction it needs to turn and is used for the remainder of the program’s execution.
2) Suboptimal scenario - the robot sets a target directly in front of it, and begins to drive forwards towards the target, not knowing which direction it needs to turn, and constantly repeats the cycle of comparing the wall lengths until it finds a clear winner.

## MAIN EXECUTION LOOP

Enters a new segment:

- The robot sets a target on the other side of the map and begins to navigate to that target using the A* path finding algorithm, and begins to navigate to the point, avoiding the walls discovered by RANSAC.

New obstacle discovered:

- The robot is constantly looking for isolated clusters of points that do not form part of a wall. Upon discovery of such a cluster it is cross-checked with the camera. If the camera returns that there is an object of red or green colour, this is marked as a block.
- A virtual wall is drawn between the disallowed side of the block facing the facing physical wall. The A* pathfinding is then recalculated, taking this wall into account.

Three walls discovered:

- The robot updates its absolute position on the map based on the distances to these walls and the segment it is in.

Less than three walls discovered:

- The robot updates its position on the map based on the previous position and dead reckoning using the motor encoder and gyroscope.

Three laps complete:

- The robot breaks out of the loop, and the program exits.

Default:

- The robot attempts to drive in the direction in between its current position and next waypoint as defined by the A* pathfinding.

# Code

## LiDAR

Code Link (https://github.com/Michael-she/Chiuahua-MK8/blob/main/SRC/lidar/basic_display.py)

This code is responsible for interpreting the serial data from the LiDAR module. The polar coordinates output by the LiDAR module are mapped and saved, allowing inferences and decisions to be made based on their layout.

We were not able to get the CRC functionality working with the LiDAR module, despite trying a large amount of CRC algorithms, including but not limited to:

CRC-32

CRC-32C

CRC-16/MODBUS

CRC-16/CCITT-FALSE

CRC-8/DALLAS-MAXIM

CRC-5/USB

CRC-16/USB

CRC-1

As a result of this, some filtering is required to remove points generated from obviously “bad” data. These filters are as follows:

- Remove any point beyond 3.5m of range (The maximum distance between any two points on the track is 3 meters).
- Remove "lonely" points. Isolated points without a set number of other points within a specific radius.

## GYROSCOPE

Code Link (https://github.com/Michael-she/Chiuahua-MK8/blob/main/SRC/gyro/angle.py)

This code constantly polls the current angle of the gyroscope using the I2C functionality of the Raspberry Pi. It is responsible for the initial calibration of the gyroscope upon device startup.

We discovered that it is highly crucial that the 12C bus runs at 400Khz instead of the standard 100Khz, as we had previously doing. In order to do this, the 12C clock speed on the Raspberry Pi had to be changed. This can be accomplished using the following steps:

1. Open the terminal on your Raspberry Pi.
2. Launch the config.txt file at file/boot/firmware/config.txt in a text editor.
3. Add or modify the I2C baudrate line, replacing REPLACE_WITH_VALUE with your desired clock speed in Hertz.
4. Save the file and exit the editor.
5. Reboot the Raspberry Pi for the changes to take effect.

## SERVO

Code Link (https://github.com/Michael-she/Chiuahua-MK8/blob/main/SRC/gyro/yaw_gyro.py)

This code continuously adjusts the servo to keep the true angle of the vehicle as measured by the gyroscope, as close as possible to a target angle which is set programmatically. This is done continuously through the use of a simple proportional function.

## CAMERA

Code Link (https://github.com/Michael-she/Chiuahua-MK8/blob/main/SRC/camera/cameraManager.py)

The camera program is queried with an angle, it will then respond with the colour of any detected blocks at the angle.

## MOTOR

Code Link (https://github.com/Michael-she/Chiuahua-MK8/blob/main/SRC/motor/motor_controller.py)

A target rpm is passed into this program. This program then adjusts the motor power output up and down in an attempt to maintain this RPM constantly. This is done to attempt to maintain a constant speed, while certain actions (such as turning the robot sharply) may require more or less power to perform at said speed in comparison to normal operations.

The PWM control of the motor proved to be a challenge: Below a certain frequency, the PWM control was ineffective, while above a certain frequency, the motor would experience symptoms of the “flyback effect”. This would cause the motor to instantly lose power at power levels below 100%. The cause and consequences of the flyback effect are well explained in this video by ElectricMonkeyBrain. (https://www.youtube.com/watch?v=QxCqmxqU-5M)

## NAVIGATION

Code Link (https://github.com/Michael-she/Chiuahua-MK8/blob/main/SRC/The%20Taxi/taxiDriver.py)

The details of this Navigation program are covered in the “Obstacle Management” section.

## SIMULATION

Code Link (https://github.com/Michael-she/Chiuahua-MK8/tree/main/SRC/Simulation)

Before any hardware was built, the theory and algorithms powering the robot needed to be tested. Therefore, we wrote a series of python programs to simulate the robot on the game board environment. These programs also allowed for experimentation with, as well as the tuning of, algorithms such as A* (pathfinding) and RANSAC (wall detection).

Unfortunately, there was a major flaw in all the simulation programs written to date. The simulation programs used an absolute reference position, whereas the robot uses a relative reference position, where it is always placed at the center. This means that the simulation programs did not provide a near “drag and drop” solution to software as we had hoped.

Additionally, RANSAC wall detection did not translate well into the real world, due to a combination of noisy LiDAR data, and the processing power limitations of the Raspberry Pi 4B we were using.

# Assembly Instructions

## MECHANICAL ASSEMBLY

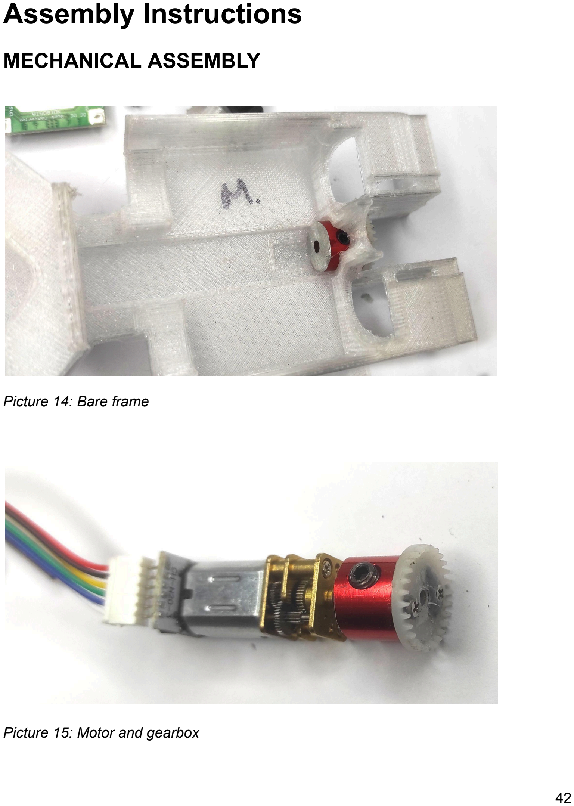
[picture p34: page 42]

Picture 14: Bare frame

Picture 15: Motor and gearbox

Picture 16: Motor and gearbox fitted in frame

Pictures 17 & 18: Wheel bearing fitted and glued

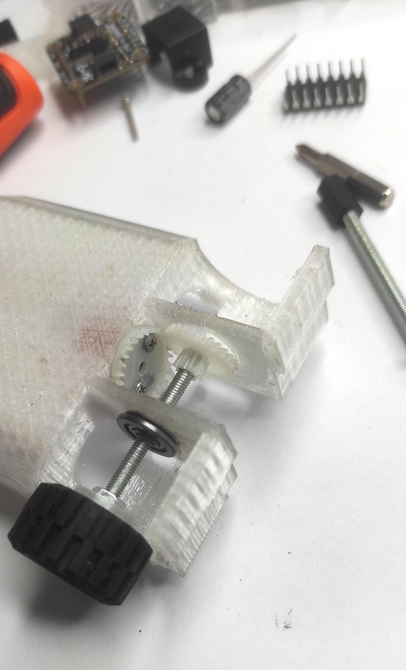
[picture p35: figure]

Picture 19: Wheel axle fitted through bearing and gear attached

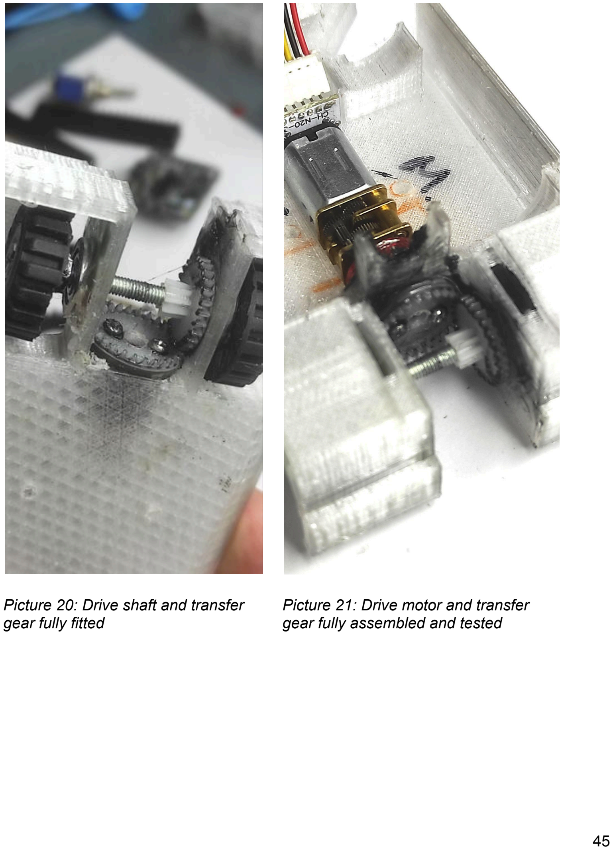
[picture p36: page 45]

Picture 20: Drive shaft and transfer gear fully fitted

Picture 21: Drive motor and transfer gear fully assembled and tested

## MOTOR DRIVER ELECTRONIC ASSEMBLY

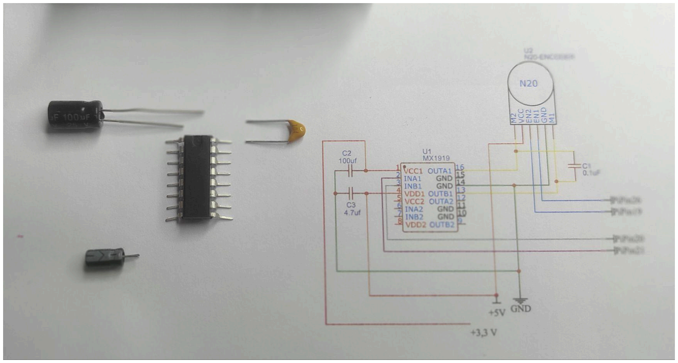
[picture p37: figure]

Picture 22

Parts required:

- Driver chip Mx1919
- 100 UF capacitor
- 4.7 UF capacitor
- 0.1 UF capacitor (104)

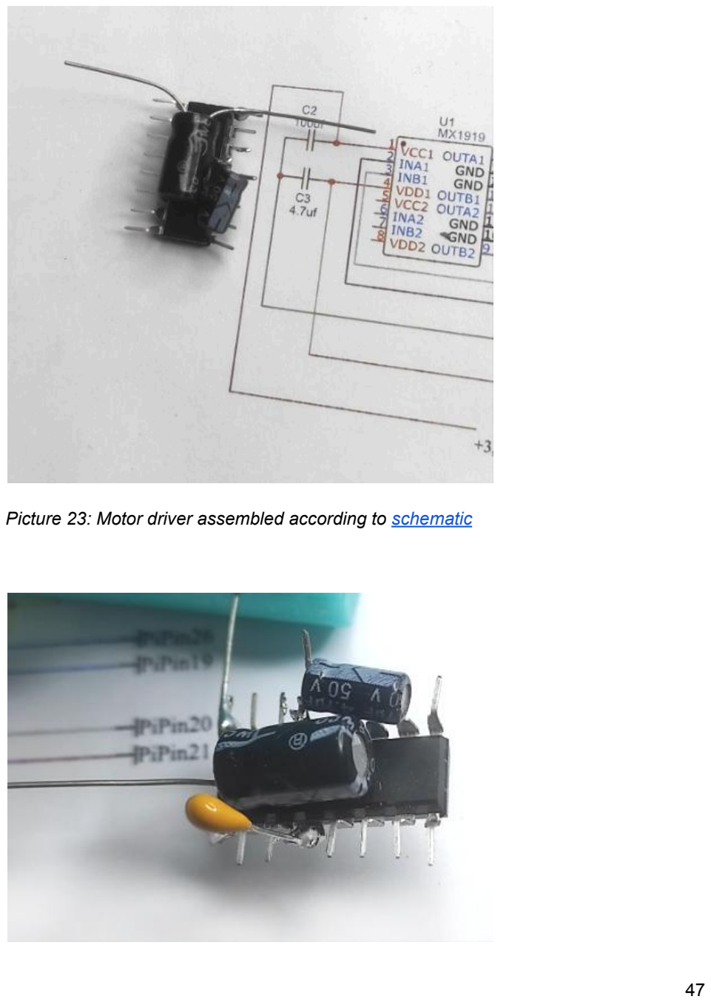
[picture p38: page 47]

Picture 23: Motor driver assembled according to schematic

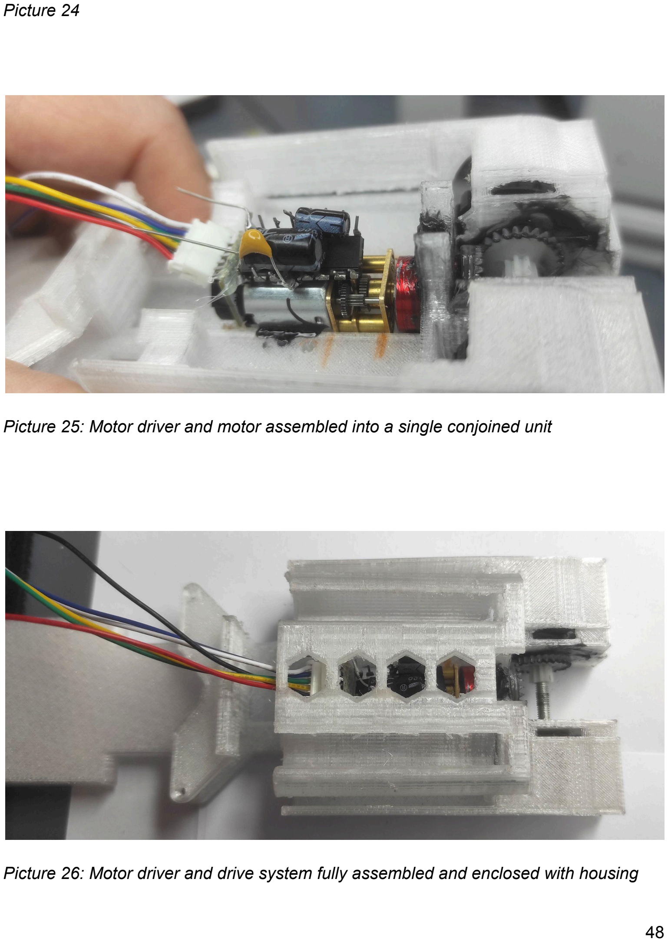
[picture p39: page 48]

Picture 24

Picture 25: Motor driver and motor assembled into a single conjoined unit

Picture 26: Motor driver and drive system fully assembled and enclosed with housing

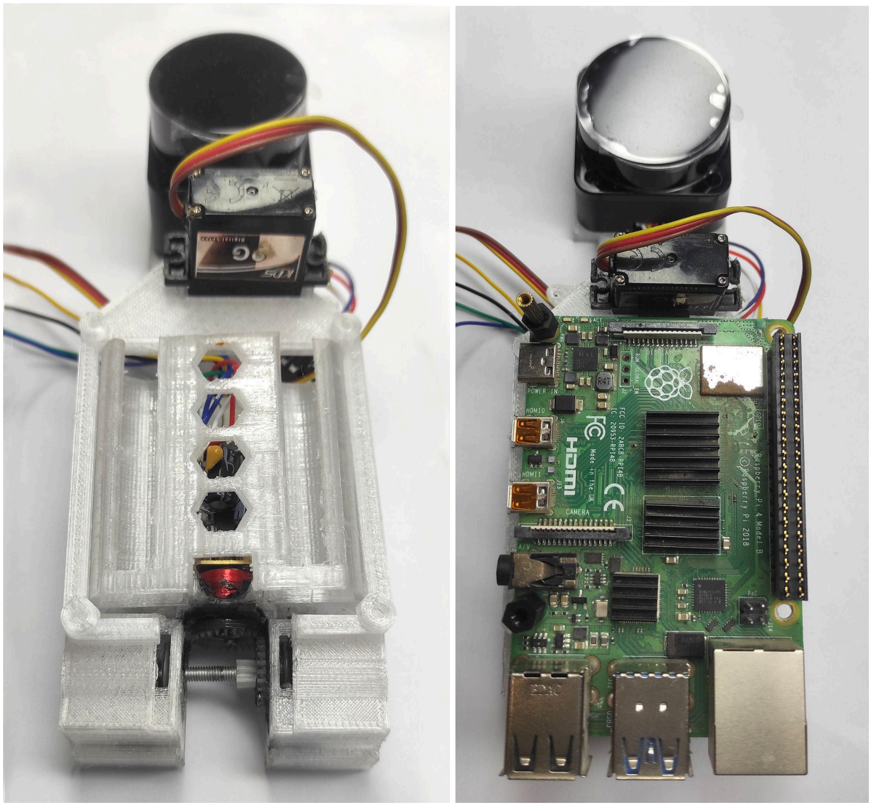
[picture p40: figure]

Picture 27: Steering servo and LiDAR placed Picture 28: Raspberry Pi fitted on housing

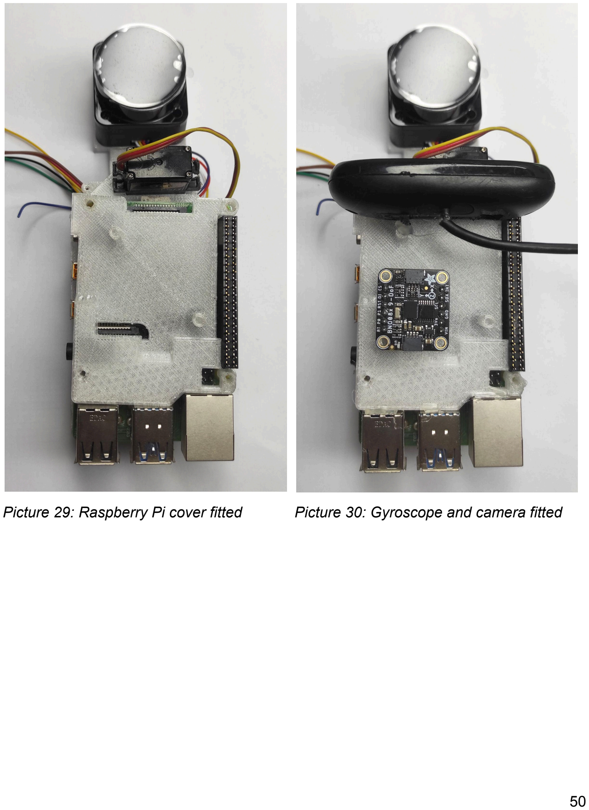
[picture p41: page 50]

Picture 29: Raspberry Pi cover fitted | Picture 30: Gyroscope and camera fitted

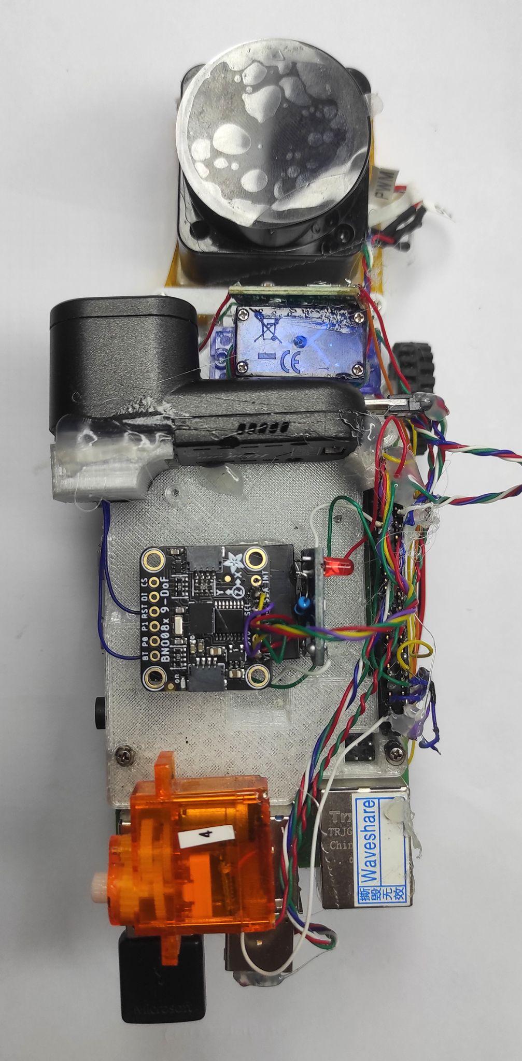
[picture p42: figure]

Picture 31: Full assembly including wiring completed

# Performance Videos

The final demonstration videos for both the Open Category and the Obstacle Course (both counter-clockwise) are linked below:

Open Category (with Obstacle Course):

https://drive.google.com/file/d/1dCYkma0lkvMgx6yHIK88wNyot38AUz7H/view?usp=sha ring (https://drive.google.com/file/d/1dCYkma0lkvMgx6yHIK88wNyot38AUz7H/view?usp=sharing)

Obstacle Course:

https://drive.google.com/file/d/1bYNcN9EtOQiN2dTkUOJqgeJ6sqKyGN7H/view?usp=s haring (https://drive.google.com/file/d/1bYNcN9EtOQiN2dTkUOJqgeJ6sqKyGN7H/view?usp=sharing)

Footage from practice session at National competition:

Open Category

https://mega.nz/file/msoVmCoZ#UEwlKEFltULUJovgpT9y6ZBriwbR0sIAhkQwHC421l4

Obstacle Course

https://mega.nz/file/KxhHzBLK#E4nYZPk7t2at33ARv7HDcp-X8Sl2K3j7b9YJdq0xiP0

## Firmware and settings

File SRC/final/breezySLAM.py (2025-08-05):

# run_slam_final.py
# Final version with correct API usage for BreezySLAM

import threading
import collections
import time
import math
import pygame
import numpy as np
import serial
import RPi.GPIO as GPIO
import struct

# --- Import Your Hardware Drivers and SLAM ---
from n20_motor import N20Motor
import board
import busio
from adafruit_bno08x.i2c import BNO08X_I2C
from adafruit_bno08x import BNO_REPORT_ROTATION_VECTOR

from breezyslam.algorithms import RMHC_SLAM
from breezyslam.sensors import Laser

# --- Hardware and SLAM Configuration ---
WHEEL_DIAMETER_M = 0.020
MOTOR_FWD_PIN = 20
MOTOR_REV_PIN = 16
MOTOR_ENCODER_A_PIN = 27 # Using a safe pin
MOTOR_PULSES_PER_REVOLUTION = 200
LIDAR_SERIAL_PORT = '/dev/serial0'
LIDAR_BAUD_RATE = 230400
LIDAR_PWM_PIN = 18
LIDAR_MOTOR_DUTY_CYCLE = 65
MAP_SIZE_PIXELS = 800
MAP_SIZE_METERS = 20
LIDAR_MAX_RANGE_MM = 3000

# --- Thread-Safe Shared Data ---
lidar_points_polar = collections.deque(maxlen=450)
stop_event = threading.Event()
yaw_lock = threading.Lock()
current_yaw_deg = 0.0
yaw_offset = 0.0

# --- ALL THREADS AND HELPER FUNCTIONS ARE UNCHANGED ---
# (Omitting them here for brevity, paste your working versions in)
def gyro_reader_thread():
    # ... (Your working gyro_reader_thread code) ...
    global current_yaw_deg, yaw_offset
    try:
        i2c = busio.I2C(board.SCL, board.SDA)
        bno = BNO08X_I2C(i2c)
        bno.enable_feature(BNO_REPORT_ROTATION_VECTOR)
    except Exception as e:
        print(f"FATAL: Could not initialize BNO08x: {e}")
        stop_event.set(); return

    print("Calibrating gyroscope... Do not move the robot.")
    time.sleep(1.5)
    try:
        quat_initial = bno.quaternion
        yaw_offset = calculate_yaw(quat_initial)
        print(f"Gyro calibrated. Initial yaw offset: {yaw_offset:.2f} degrees.")
    except Exception as e:
        print(f"WARNING: Could not calibrate gyro: {e}. Using zero offset.")
        yaw_offset = 0.0

    while not stop_event.is_set():
        try:
            quat = bno.quaternion
            raw_yaw = calculate_yaw(quat)
            with yaw_lock:
                calibrated_yaw = raw_yaw - yaw_offset
                current_yaw_deg = (calibrated_yaw + 180) % 360 - 180
        except (RuntimeError, KeyError):
            time.sleep(0.01)
            continue
        time.sleep(0.01)

def calculate_yaw(quaternion):
    # ... (Your working calculate_yaw code) ...
    q_i, q_j, q_k, q_real = quaternion
    siny_cosp = 2 * (q_real * q_k + q_i * q_j)
    cosy_cosp = 1 - 2 * (q_j * q_j + q_k * q_k)
    return math.degrees(math.atan2(siny_cosp, cosy_cosp))

def lidar_reader_thread():
    # ... (Your working lidar_reader_thread code) ...
    try:
        ser = serial.Serial(LIDAR_SERIAL_PORT, LIDAR_BAUD_RATE, timeout=0.1)
    except serial.SerialException as e:
        print(f"FATAL: Could not open LiDAR serial port: {e}")
        stop_event.set(); return

    GPIO.setmode(GPIO.BCM)
    GPIO.setwarnings(False)
    GPIO.setup(LIDAR_PWM_PIN, GPIO.OUT)
    motor_pwm = GPIO.PWM(LIDAR_PWM_PIN, 1000)
    motor_pwm.start(LIDAR_MOTOR_DUTY_CYCLE)
    print("LiDAR motor started. Reader thread running.")

    packet_buffer = bytearray()
    while not stop_event.is_set():
        try:
            data = ser.read(4096)
            if not data: time.sleep(0.001); continue
            packet_buffer.extend(data)
            while len(packet_buffer) >= 47:
                header_index = packet_buffer.find(b'\x54')
                if header_index == -1: packet_buffer.clear(); break
                if header_index > 0: packet_buffer = packet_buffer[header_index:]
                if len(packet_buffer) < 47: break
                packet = packet_buffer[:47]
                start_angle = struct.unpack('<H', bytes(packet[4:6]))[0]
                end_angle = struct.unpack('<H', bytes(packet[42:44]))[0]
                start_angle_deg = start_angle / 100.0
                end_angle_deg = end_angle / 100.0
                angle_diff = end_angle_deg - start_angle_deg
                if angle_diff < 0: angle_diff += 360.0
                for i in range(12):
                    offset = 6 + (i * 3)
                    distance_mm = struct.unpack('<H', bytes(packet[offset:offset+2]))[0]
                    confidence = packet[offset+2]
                    if confidence > 180:
                        angle_step = angle_diff / 11 if 11 > 0 else 0
                        current_angle_deg = start_angle_deg + i * angle_step
                        lidar_points_polar.append((math.radians(current_angle_deg % 360), distance_mm))
                packet_buffer = packet_buffer[47:]
        except Exception as e:
            print(f"Error in LiDAR reader thread: {e}"); break
    motor_pwm.stop()
    GPIO.cleanup(LIDAR_PWM_PIN)
    ser.close()
    print("LiDAR reader thread has stopped.")
    
class RealOdometry:
    # ... (Your working RealOdometry class code) ...
    def __init__(self, motor, initial_x_m, initial_y_m):
        self.motor = motor
        self.x_m = initial_x_m
        self.y_m = initial_y_m
        self.theta_deg = 0.0
        self.wheel_circumference_m = WHEEL_DIAMETER_M * math.pi
        self.last_revolutions = self.motor.get_revolutions()

    def get_odometry(self):
        current_revolutions = self.motor.get_revolutions()
        with yaw_lock:
            self.theta_deg = current_yaw_deg
        delta_revolutions = current_revolutions - self.last_revolutions
        distance_traveled_m = delta_revolutions * self.wheel_circumference_m
        theta_rad = math.radians(self.theta_deg)
        self.x_m += distance_traveled_m * math.cos(theta_rad)
        self.y_m += distance_traveled_m * math.sin(theta_rad)
        self.last_revolutions = current_revolutions
        return [self.x_m, self.y_m, self.theta_deg]

# --- Main Application (with corrected API calls) ---
# --- Main Application (with correct scan padding logic) ---
def main():
    pygame.init()
    screen = pygame.display.set_mode((MAP_SIZE_PIXELS, MAP_SIZE_PIXELS))
    pygame.display.set_caption("BreezySLAM - Use Arrow Keys to Move")
    font = pygame.font.SysFont(None, 30)
    map_surface = pygame.Surface((MAP_SIZE_PIXELS, MAP_SIZE_PIXELS))

    map_bytes = bytearray(MAP_SIZE_PIXELS * MAP_SIZE_PIXELS)
    
    motor = N20Motor(fwd_pin=MOTOR_FWD_PIN, rev_pin=MOTOR_REV_PIN, enc_a_pin=MOTOR_ENCODER_A_PIN, pulses_per_revolution=MOTOR_PULSES_PER_REVOLUTION)
    
    try:
        gyro_thread = threading.Thread(target=gyro_reader_thread)
        gyro_thread.daemon = True
        gyro_thread.start()
        lidar_thread = threading.Thread(target=lidar_reader_thread)
        lidar_thread.daemon = True
        lidar_thread.start()

        print("Waiting for hardware to initialize and calibrate...")
        time.sleep(3)

        # We promise a 360-point scan. This is the correct size.
        SCAN_SIZE = 360
        slam = RMHC_SLAM(Laser(SCAN_SIZE, 7, 0, 0), MAP_SIZE_PIXELS, MAP_SIZE_METERS)
        odometry = RealOdometry(motor, MAP_SIZE_METERS / 2, MAP_SIZE_METERS / 2)
        motor_speed = 0
        
        running = True
        while running:
            for event in pygame.event.get():
                if event.type == pygame.QUIT or (event.type == pygame.KEYDOWN and event.key == pygame.K_ESCAPE): running = False
                if event.type == pygame.KEYDOWN:
                    if event.key == pygame.K_UP: motor_speed = 40
                    elif event.key == pygame.K_DOWN: motor_speed = -40
                if event.type == pygame.KEYUP:
                    if event.key in [pygame.K_UP, pygame.K_DOWN]: motor_speed = 0
            motor.set_speed(motor_speed)

            current_odometry = odometry.get_odometry()

            # --- SCAN PADDING LOGIC ---
            
            # 1. Create an empty scan of the correct size
            scan_distances_mm = [0] * SCAN_SIZE
            
            points_to_process = list(lidar_points_polar)
            for angle_rad, distance_mm in points_to_process:
                if 0 < distance_mm < LIDAR_MAX_RANGE_MM:
                    # 2. Calculate the correct index (0-359) for this measurement
                    index = int(math.degrees(angle_rad)) % SCAN_SIZE
                    # 3. Place the measurement in its slot
                    scan_distances_mm[index] = distance_mm

            # 4. Deliver the perfectly-sized list to SLAM
            slam.update(scan_distances_mm, current_odometry)

            x_m, y_m, theta_deg = slam.getpos()
            slam.getmap(map_bytes)

            gray_map = np.frombuffer(map_bytes, dtype=np.uint8).reshape((MAP_SIZE_PIXELS, MAP_SIZE_PIXELS))
            display_map = np.stack([gray_map]*3, axis=-1)

            pygame.surfarray.blit_array(map_surface, display_map)
            screen.blit(map_surface, (0, 0))
            
            robot_x_pix = int(x_m / MAP_SIZE_METERS * MAP_SIZE_PIXELS)
            robot_y_pix = int(y_m / MAP_SIZE_METERS * MAP_SIZE_PIXELS)
            pygame.draw.circle(screen, (255, 0, 0), (robot_x_pix, robot_y_pix), 5)
            theta_rad = math.radians(theta_deg)
            end_x = robot_x_pix + 15 * math.cos(theta_rad)
            end_y = robot_y_pix + 15 * math.sin(theta_rad)
            pygame.draw.line(screen, (255, 0, 0), (robot_x_pix, robot_y_pix), (end_x, end_y), 2)
            
            pose_text = f"Pose: ({x_m:.2f}m, {y_m:.2f}m, {theta_deg:.1f}°)"
            text_surface = font.render(pose_text, True, (255, 255, 0))
            screen.blit(text_surface, (10, 10))
            pygame.display.flip()
            
    finally:
        # ... The rest of the finally block is correct ...
        print("Stopping all processes and cleaning up...")
        stop_event.set()
        motor.stop()
        motor.cleanup()
        
        if 'lidar_thread' in locals() and lidar_thread.is_alive(): lidar_thread.join()
        if 'gyro_thread' in locals() and gyro_thread.is_alive(): gyro_thread.join()

        if 'slam' in locals():
            with open('slam_map_final.pgm', 'wb') as f:
                pgm_header = f"P5\n{MAP_SIZE_PIXELS} {MAP_SIZE_PIXELS}\n255\n".encode()
                f.write(pgm_header)
                f.write(map_bytes)
            print("Map saved to slam_map_final.pgm")
        
        pygame.quit()
        print("Program finished cleanly.")

        
if __name__ == '__main__':
    # Paste your other functions (gyro, lidar, odometry class) here
    main()

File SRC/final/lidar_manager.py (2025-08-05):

# lidar_main.py
# This script is the final, high-performance implementation based on all our findings.
# It uses a checksum-agnostic reader in a separate thread and a fast Pygame renderer.
# MODIFIED to include an isolation filter and RANSAC for wall detection.
# CORRECTED to properly handle MAX_POINT_DISTANCE_MM for wall clustering.
# CORRECTED to show a static robot arrow, as the view is robot-centric.

import serial
import RPi.GPIO as GPIO
import time
import struct
import math
import pygame
import threading
import collections
import random
import numpy as np # Required for RANSAC's PCA line fitting

# --- Thread-Safe Shared Data Structure ---
lidar_points_polar = collections.deque(maxlen=450)
stop_event = threading.Event()

# --- LiDAR and GPIO Configuration ---
PWM_PIN = 18
SERIAL_PORT = '/dev/serial0'
BAUD_RATE = 230400
MOTOR_DUTY_CYCLE = 65

# --- Pygame Configuration ---
SCREEN_WIDTH = 800
SCREEN_HEIGHT = 800
MAX_VIZ_DISTANCE_MM = 4000
SCALE_FACTOR = MAX_VIZ_DISTANCE_MM / (SCREEN_WIDTH / 2 - 20)
BACKGROUND_COLOR = (10, 10, 10)
POINT_COLOR = (100, 200, 255)
FILTERED_POINT_COLOR = (0, 100, 255)
WALL_COLOR = (100, 255, 100)
DISTANCE_LINE_COLOR = (0, 170, 255)
DISTANCE_TEXT_COLOR = (255, 255, 255)
ARROW_COLOR = (255, 165, 0) # Orange for the arrow
ARROW_LENGTH_PX = 60
ARROW_HEAD_LENGTH_PX = 20
ARROW_HEAD_ANGLE_DEG = 150

# --- Filter and RANSAC Configuration ---
LIDAR_RANGE_MM = 3000.0
ISOLATION_DISTANCE_MM = 60.0
ISOLATION_MIN_NEIGHBORS = 3
RANSAC_ITERATIONS = 25
RANSAC_THRESHOLD_MM = 80.0
RANSAC_MIN_INLIERS = 50
MAX_POINT_DISTANCE_MM = 80.0
MIN_WALL_LENGTH_MM = 150.0

# --- Direction Detection Configuration ---
DIRECTION_TOLERANCE_MM = 150.0 # Wall lengths must differ by this much to determine direction

# --- LiDAR Reader Thread (Unchanged) ---
def lidar_reader_thread():
    """Reads data from LiDAR and puts valid points into the shared deque."""
    try:
        ser = serial.Serial(SERIAL_PORT, BAUD_RATE, timeout=0.1)
    except serial.SerialException as e:
        print(f"FATAL: Could not open serial port: {e}")
        stop_event.set(); return

    GPIO.setmode(GPIO.BCM)
    GPIO.setwarnings(False)
    GPIO.setup(PWM_PIN, GPIO.OUT)
    motor_pwm = GPIO.PWM(PWM_PIN, 1000)
    motor_pwm.start(MOTOR_DUTY_CYCLE)
    print("Motor started. Reader thread running.")

    packet_buffer = bytearray()
    while not stop_event.is_set():
        try:
            data = ser.read(4096)
            if not data:
                time.sleep(0.001); continue
            packet_buffer.extend(data)
            while len(packet_buffer) >= 47:
                header_index = packet_buffer.find(0x54)
                if header_index == -1:
                    packet_buffer.clear(); break
                if header_index > 0:
                    packet_buffer = packet_buffer[header_index:]
                if len(packet_buffer) < 47: break
                packet = packet_buffer[:47]
                start_angle = struct.unpack('<H', bytes(packet[4:6]))[0]
                end_angle = struct.unpack('<H', bytes(packet[42:44]))[0]
                start_angle_deg = start_angle / 100.0
                end_angle_deg = end_angle / 100.0
                angle_diff = end_angle_deg - start_angle_deg
                if angle_diff < 0: angle_diff += 360.0
                for i in range(12):
                    offset = 6 + (i * 3)
                    distance_mm = struct.unpack('<H', bytes(packet[offset:offset+2]))[0]
                    confidence = packet[offset+2]
                    if distance_mm > 0 and confidence > 180:
                        angle_step = angle_diff / 11 if 11 > 0 else 0
                        current_angle_deg = start_angle_deg + i * angle_step
                        lidar_points_polar.append((math.radians(current_angle_deg % 360), distance_mm))
                packet_buffer = packet_buffer[47:]
        except Exception as e:
            print(f"Error in reader thread: {e}"); break
    motor_pwm.stop()
    GPIO.cleanup()
    ser.close()
    print("Reader thread has stopped.")


# --- Helper Functions (Existing functions are unchanged) ---
def filter_isolated_points(cartesian_points, min_neighbors, isolation_radius):
    if not cartesian_points: return []
    grid_cell_size = isolation_radius
    grid = collections.defaultdict(list)
    for i, point in enumerate(cartesian_points):
        cell = (int(point[0] // grid_cell_size), int(point[1] // grid_cell_size))
        grid[cell].append(i)
    filtered_points = []
    isolation_radius_sq = isolation_radius ** 2
    for i, p1 in enumerate(cartesian_points):
        neighbor_count = 0
        p1_cell = (int(p1[0] // grid_cell_size), int(p1[1] // grid_cell_size))
        for dx in [-1, 0, 1]:
            for dy in [-1, 0, 1]:
                check_cell = (p1_cell[0] + dx, p1_cell[1] + dy)
                if check_cell in grid:
                    for neighbor_idx in grid[check_cell]:
                        p2 = cartesian_points[neighbor_idx]
                        dist_sq = (p1[0] - p2[0])**2 + (p1[1] - p2[1])**2
                        if dist_sq < isolation_radius_sq:
                            neighbor_count += 1
        if neighbor_count >= min_neighbors:
            filtered_points.append(p1)
    return filtered_points

def distance_from_point_to_line(p, l1, l2):
    x0, y0 = p; x1, y1 = l1; x2, y2 = l2
    num = abs((y2 - y1) * x0 - (x2 - x1) * y0 + x2 * y1 - y2 * x1)
    den = math.sqrt((y2 - y1)**2 + (x2 - x1)**2)
    return num / den if den != 0 else 0

def fit_line_with_pca(points):
    if len(points) < 2: return None
    data = np.array(points)
    mean = np.mean(data, axis=0)
    _, eigenvectors = np.linalg.eigh(np.cov(data.T))
    direction_vector = eigenvectors[:, -1]
    projections = np.dot(data - mean, direction_vector)
    p1 = mean + np.min(projections) * direction_vector
    p2 = mean + np.max(projections) * direction_vector
    return (p1.tolist(), p2.tolist())

def cluster_inliers_by_distance(inliers, max_distance):
    if not inliers: return []
    data = np.array(inliers)
    mean = np.mean(data, axis=0)
    _, eigenvectors = np.linalg.eigh(np.cov(data.T))
    direction_vector = eigenvectors[:, -1]
    projected = sorted([(np.dot(p - mean, direction_vector), p) for p in inliers], key=lambda x: x[0])
    sorted_inliers = [p for _, p in projected]
    clusters, current_cluster = [], [sorted_inliers[0]]
    for i in range(1, len(sorted_inliers)):
        p1, p2 = sorted_inliers[i-1], sorted_inliers[i]
        if math.hypot(p1[0] - p2[0], p1[1] - p2[1]) < max_distance:
            current_cluster.append(p2)
        else:
            clusters.append(current_cluster)
            current_cluster = [p2]
    clusters.append(current_cluster)
    return clusters
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

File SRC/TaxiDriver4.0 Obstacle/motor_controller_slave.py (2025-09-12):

#!/usr/bin/env python3
"""
Simple Motor Controller with Encoder Support
Controls a motor using PWM on pins 20/21 with encoder feedback on pins 19/13.
"""

import RPi.GPIO as GPIO
import time
import threading
import multiprocessing

class SimpleMotorController:
    def __init__(self, pin1=21, pin2=20, encoder_pin_a=19, encoder_pin_b=13, pwm_frequency= 2000):
        """
        Initialize Simple Motor Controller with direction control and encoder support
        
        Args:
            pin1 (int): Motor pin 1 (default: 20)
            pin2 (int): Motor pin 2 (default: 21)
            encoder_pin_a (int): Encoder channel A (default: 19)
            encoder_pin_b (int): Encoder channel B (default: 13)
            pwm_frequency (int): PWM frequency in Hz (default: 20000)
        """
        self.pin1 = pin1
        self.pin2 = pin2
        self.encoder_pin_a = encoder_pin_a
        self.encoder_pin_b = encoder_pin_b
        self.pwm_frequency = pwm_frequency
        self.pwm1 = None
        self.pwm2 = None
        self.current_speed = 0
        self.current_direction = 1  # 1 for forward, -1 for reverse
        
        # Encoder variables
        self.encoder_count = 0
        self.encoder_lock = threading.Lock()
        self.last_encoder_a = 0
        self.last_encoder_b = 0
        self.polling_active = False
        self.polling_thread = None
        
        self._setup_gpio()
        print("Simple Motor Controller with Direction Control and Encoders initialized")
        print(f"Motor pins: {self.pin1}, {self.pin2}")
        print(f"Encoder pins: {self.encoder_pin_a}, {self.encoder_pin_b}")
        print(f"PWM frequency: {self.pwm_frequency} Hz")
    
    def _setup_gpio(self):
        """Setup GPIO pins for bidirectional control and encoders"""
        try:
            # Set GPIO mode
            GPIO.setmode(GPIO.BCM)
            GPIO.setwarnings(False)
            
            # Clean up any existing setup
            try:
                GPIO.cleanup()
                time.sleep(0.1)
            except:
                pass
            
            # Setup both motor pins as outputs
            GPIO.setup(self.pin1, GPIO.OUT)
            GPIO.setup(self.pin2, GPIO.OUT)
            
            # Setup encoder pins as inputs with pull-up resistors
            GPIO.setup(self.encoder_pin_a, GPIO.IN, pull_up_down=GPIO.PUD_UP)
            GPIO.setup(self.encoder_pin_b, GPIO.IN, pull_up_down=GPIO.PUD_UP)
            
            # Setup PWM on both pins
            self.pwm1 = GPIO.PWM(self.pin1, self.pwm_frequency)
            self.pwm2 = GPIO.PWM(self.pin2, self.pwm_frequency)
            
            # Start both PWM with 0% duty cycle
            self.pwm1.start(0)
            self.pwm2.start(0)
            
            # Setup encoder interrupts
            self._setup_encoder_interrupts()
            
            print("GPIO setup completed")
            
        except Exception as e:
            print(f"Error during GPIO setup: {e}")
            self.cleanup()
            raise
    
    def _setup_encoder_interrupts(self):
        """Setup encoder interrupt handling with fallback to polling"""
        try:
            # Try to set up interrupts
            GPIO.add_event_detect(self.encoder_pin_a, GPIO.BOTH, callback=self._encoder_callback, bouncetime=1)
            print("Encoder interrupts enabled")
        except Exception as e:
            print(f"Warning: Could not setup encoder interrupts: {e}")
            print("Falling back to polling method")
            # Start polling thread as fallback
            self.polling_thread = threading.Thread(target=self._encoder_polling, daemon=True)
            self.polling_active = True
            self.polling_thread.start()
    
    def _encoder_callback(self, channel):
        """Encoder interrupt callback for quadrature decoding"""
        try:
            with self.encoder_lock:
                # Read current states
                state_a = GPIO.input(self.encoder_pin_a)
                state_b = GPIO.input(self.encoder_pin_b)
                
                # Simple quadrature decoding
                if state_a != self.last_encoder_a:
                    if state_a == state_b:
                        self.encoder_count += 1
                    else:
                        self.encoder_count -= 1
                
                self.last_encoder_a = state_a
                self.last_encoder_b = state_b
        except Exception as e:
            print(f"Encoder callback error: {e}")
    
    def _encoder_polling(self):
        """Fallback polling method for encoder reading"""
        try:
            last_a = GPIO.input(self.encoder_pin_a)
            last_b = GPIO.input(self.encoder_pin_b)
            
            while getattr(self, 'polling_active', True):
                try:
                    current_a = GPIO.input(self.encoder_pin_a)
                    current_b = GPIO.input(self.encoder_pin_b)
                    
                    if current_a != last_a:
                        with self.encoder_lock:
                            if current_a == current_b:
                                self.encoder_count += 1
                            else:
                                self.encoder_count -= 1
                    
                    last_a = current_a
                    last_b = current_b
                    time.sleep(0.001)  # 1ms polling interval
                except Exception as e:
                    print(f"Encoder polling error: {e}")
                    break
        except Exception as e:
            print(f"Error starting encoder polling: {e}")
    
    def set_speed(self, speed_percent, direction=None):
        """
        Set motor speed and direction
        
        Args:
            speed_percent (float): Speed as percentage (0-100)
            direction (int, optional): 1 for forward, -1 for reverse
        """
        try:
            # Clamp speed to valid range
            speed_percent = max(0, min(100, speed_percent))
            
            # Update direction if specified
            if direction is not None:
                self.current_direction = 1 if direction > 0 else -1
            
            self.current_speed = speed_percent
            
            if self.pwm1 is not None and self.pwm2 is not None:
                if speed_percent == 0:
                    # Stop motor - both pins to 0
                    self.pwm1.ChangeDutyCycle(0)
                    self.pwm2.ChangeDutyCycle(0)
                    print("Motor stopped")
                elif self.current_direction == 1:
                    # Forward - PWM on pin1, pin2 low
                    self.pwm1.ChangeDutyCycle(speed_percent)
                    self.pwm2.ChangeDutyCycle(0)
                    print(f"Motor FORWARD at {speed_percent}%")
                else:
                    # Reverse - PWM on pin2, pin1 low
                    self.pwm1.ChangeDutyCycle(0)
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

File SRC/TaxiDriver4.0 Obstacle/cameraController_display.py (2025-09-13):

import cv2
import sys
import os
import time
import numpy as np
from datetime import datetime

# Set display for OpenCV
os.environ['DISPLAY'] = ':0'

# Import relay control functions    
try:
    from relay_control import setup_gpio, activate_relay, cleanup
    RELAY_AVAILABLE = True
    print("Relay control module imported successfully")
except ImportError as e:
    RELAY_AVAILABLE = False
    print(f"Warning: Could not import relay control: {e}")

# Adjust the camera_index if you have multiple cameras or if 0 doesn't work.
camera_index = 0
MAX_CAMERA_RETRIES = 2
RETRY_DELAY = 10

def try_open_camera(index, attempt=1):
    """Attempt to open camera with retry logic and relay activation"""
    print(f"Attempt {attempt}: Trying to open camera with index {index}...")
    cap = cv2.VideoCapture(index)
    
    if cap.isOpened():
        print(f"✓ Camera {index} opened successfully on attempt {attempt}!")
        return cap
    else:
        print(f"✗ Failed to open camera {index} on attempt {attempt}")
        cap.release()
        
        if attempt < MAX_CAMERA_RETRIES and RELAY_AVAILABLE:
            print("Attempting to reset camera using relay...")
            try:
                setup_gpio()
                activate_relay()
                cleanup()
                print(f"Relay activation completed. Waiting {RETRY_DELAY} seconds before retry...")
                time.sleep(RETRY_DELAY)
            except Exception as e:
                print(f"Error during relay activation: {e}")
                if 'cleanup' in globals():
                    cleanup()
        
        return None

# Try to open camera with relay reset capability
cap = None
for attempt in range(1, MAX_CAMERA_RETRIES + 1):
    cap = try_open_camera(camera_index, attempt)
    if cap is not None:
        break
    
    if attempt < MAX_CAMERA_RETRIES:
        print(f"Retrying in {RETRY_DELAY} seconds...")
        time.sleep(RETRY_DELAY)

if cap is None:
    print(f"Error: Could not open camera with index {camera_index} after {MAX_CAMERA_RETRIES} attempts.")
    print("Available video devices:")
    import subprocess
    try:
        result = subprocess.run(['ls', '/dev/video*'], capture_output=True, text=True, shell=True)
        print(result.stdout)
    except:
        print("Could not list video devices")
    sys.exit(1)

print(f"Camera {camera_index} opened successfully!")

# Set camera properties for better performance
cap.set(cv2.CAP_PROP_FRAME_WIDTH, 640)
cap.set(cv2.CAP_PROP_FRAME_HEIGHT, 480)
cap.set(cv2.CAP_PROP_FPS, 30)

# Get actual camera properties
width = int(cap.get(cv2.CAP_PROP_FRAME_WIDTH))
height = int(cap.get(cv2.CAP_PROP_FRAME_HEIGHT))
fps = cap.get(cv2.CAP_PROP_FPS)

print(f"Camera resolution: {width}x{height}")
print(f"Camera FPS: {fps}")

# Advanced camera class with object detection and angle estimation (Display Version)
class USBCameraControllerDisplay:
    def __init__(self, camera_cap, width=640, height=480):
        self.camera_cap = camera_cap
        self.frame_width = width
        self.frame_height = height
        self.current_hsv_frame = None
        self.angle_lookup_table = None
        self.camera_fov = 140
        
        # Morphological kernel for image processing
        self.morph_kernel = np.ones((5, 5), np.uint8)
        
        # Color detection bounds
        self.color_bounds = {
            'green': {'lower': np.array([35, 100, 100]), 'upper': np.array([85, 255, 255])},
            'red': {'lower1': np.array([0, 120, 70]), 'upper1': np.array([10, 255, 255]),
                    'lower2': np.array([170, 120, 70]), 'upper2': np.array([180, 255, 255])},
            'pink': {'lower': np.array([140, 100, 100]), 'upper': np.array([170, 255, 255])}
        }
        
        self._generate_angle_lookup_table(self.frame_width)
    
    def _mouse_callback(self, event, x, y, flags, param):
        if event == cv2.EVENT_LBUTTONDOWN and self.current_hsv_frame is not None:
            hsv_pixel = self.current_hsv_frame[y, x]
            print(f"Clicked at (x={x}, y={y}) - HSV Value: {hsv_pixel}")
    
    def _generate_angle_lookup_table(self, frame_width):
        self.angle_lookup_table = []
        weights = [0.8, 0.9, 1.0, 1.1, 1.2, 1.3, 1.4, 1.4, 1.3, 1.2, 1.1, 1.0, 0.9, 0.8]
        total_weight = sum(weights)
        angle_step = self.camera_fov / len(weights)
        current_pixel = 0
        for i, weight in enumerate(weights):
            angle = -self.camera_fov / 2 + (i * angle_step)
            pixel_chunk = (frame_width / total_weight) * weight
            start_pixel = int(current_pixel)
            end_pixel = int(current_pixel + pixel_chunk)
            self.angle_lookup_table.append({
                'angle': int(angle + angle_step / 2),
                'range': (start_pixel, end_pixel)
            })
            current_pixel += pixel_chunk
        print("Generated Angle Lookup Table.")
    
    def _estimate_horizontal_angle(self, object_center_x):
        if self.angle_lookup_table is None:
            return None
        for entry in self.angle_lookup_table:
            if entry['range'][0] <= object_center_x < entry['range'][1]:
                return entry['angle']
        return None
    
    def _process_contours(self, display_frame, mask, color_name, line_y):
        detections = []
        contours, _ = cv2.findContours(mask, cv2.RETR_TREE, cv2.CHAIN_APPROX_SIMPLE)
        for cnt in contours:
            if cv2.contourArea(cnt) > 150:
                x, y, w, h = cv2.boundingRect(cnt)
                if y < line_y < y + h:
                    rect = cv2.minAreaRect(cnt)
                    rotation_angle = int(rect[2])
                    object_center_x = x + w // 2
                    bearing_angle = self._estimate_horizontal_angle(object_center_x)
                    
                    # Draw on display frame
                    cv2.rectangle(display_frame, (x, y), (x + w, y + h), (0, 255, 255), 2)
                    label = f"{color_name} | Bearing: {bearing_angle}deg" if bearing_angle is not None else color_name
                    cv2.putText(display_frame, label, (x, y - 10), cv2.FONT_HERSHEY_SIMPLEX, 0.5, (0, 255, 255), 2)
                    
                    # Store detection info
                    detections.append({
                        'color': color_name,
                        'center_x': object_center_x,
                        'bearing': bearing_angle,
                        'area': cv2.contourArea(cnt),
                        'bbox': (x, y, w, h)
                    })
                    
                    # Print detection to console
                    print(f"Detected {color_name} object at bearing {bearing_angle}° (center_x: {object_center_x})")
        return detections
    
    def start_stream_display(self):
        halfway_line_y = self.frame_height // 2
        
        # Test if display is available
        try:
            window_name = 'USB Camera Feed with Object Detection'
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

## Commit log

2025-07-18 Add lidar localization and dynamic wall logic
    Introduces lidarLocaliser.py with a full lidar localization simulation, including particle filter, RANSAC wall estimation, obstacle detection, and dynamic wall generation. Updates robot_sim_mk5.py to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
2025-08-22 3d models
    [Axle Gear support type 1 v7.stl, Battery Holder.stl, Battery charger.stl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]
